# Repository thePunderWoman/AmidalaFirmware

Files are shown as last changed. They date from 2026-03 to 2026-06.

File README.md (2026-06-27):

<p align="center">
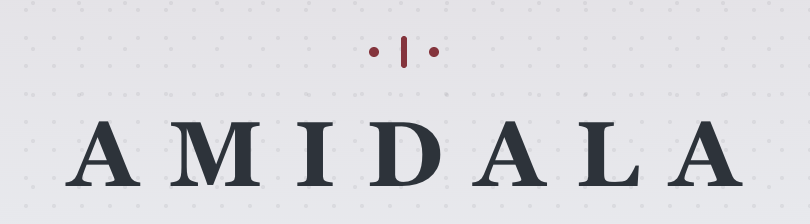
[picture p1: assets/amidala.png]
Amidala
  
</p>

<p align="center">
  <a href="https://github.com/thePunderWoman/Amidala/actions/workflows/ci.yml">
    
  </a>
  <a href="https://github.com/thePunderWoman/Amidala/releases/latest">
    
  </a>
</p>

**Amidala** is an ESP32-S3 firmware for controlling your droids. It runs on the [Amidala PCB](PCB/) — a PCB designed to make wiring a full-featured droid build straightforward — and is compatible with both the N8R2 (8 MB flash) and N16R8 (16 MB flash) module variants.

> **[Amidala Wizards →](https://thepunderwoman.github.io/Amidala/)** — browser-based tools for setting up your droid. Includes a **Config Converter** for migrating Stealth RC / OG Amidala configs to the current format.

---

## Features

- **XBee wireless control** — secure, long-range, low-latency control via XBee 3 modules
- **Multiple Controller Support** — works with classic stealth controllers, Amidala controllers, standard Bluetooth gamepads, and analog RC (PPM) input.
- **Wi-Fi configuration UI** — browser-based interface for fully configuring your droid without needing to pull the SD card.
- **Native HCR support** — full Human Cyborg Relations vocalizer integration.
- **Advanced Dome Drive** — Built-in support for auto dome drive with a Pololu encoder motor and hall sensor, or any other basic PWM dome drive.
- **Flexible drive systems** — PWM, Sabertooth serial, or RoboteQ (PWM, serial, or hybrid)
- **Native built-in safety features** — Web based e-stop, dome obstruction motor disconnect, auto motor disable on controller disconnect.
- **Layers of controller button configurations** — with short-press, long-press, and alt-modifier layers
- **Effectively unlimited serial strings and gestures** — the only limits are your imagination!
- **And more** — I2C aux output, digital outputs, analog inputs, SD card config, servo outputs, and emergency stop handling

---

## Web Configuration UI

<p align="center">
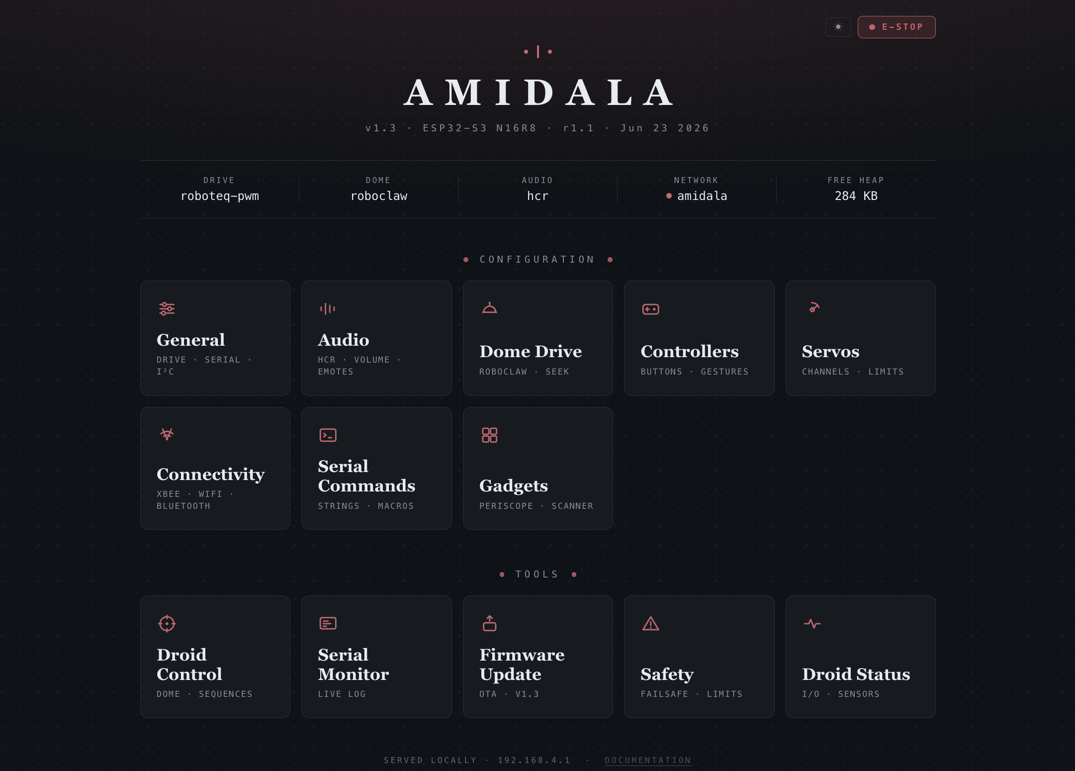
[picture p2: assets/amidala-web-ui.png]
Amidala
  
</p>

The Amidala web interface allows you total control over your droid's configuration. You can set up your controller configuration, which buttons trigger what, add serial commands, set defaults for audio, dome positioning, safety timeouts, emergency stop commands, configure Bluetooth, see digital pin statuses, use the serial monitor, configure your droid's gadgets, and even use the droid control page to trigger sequences, trigger emotes, and dome controls. See more in the wiki.

## Get Started

> **[Documentation Wiki →](https://github.com/thePunderWoman/Amidala/wiki)**

The wiki covers everything from first flash through full configuration. For a quick look at every available config key, see [example_config.txt](example_config.txt) — it's a complete annotated reference used on a real build. Although once you get set up initially, you won't need to look at this file again, as you can update every config option through the web UI.

---

## The Amidala PCB

<p align="center">
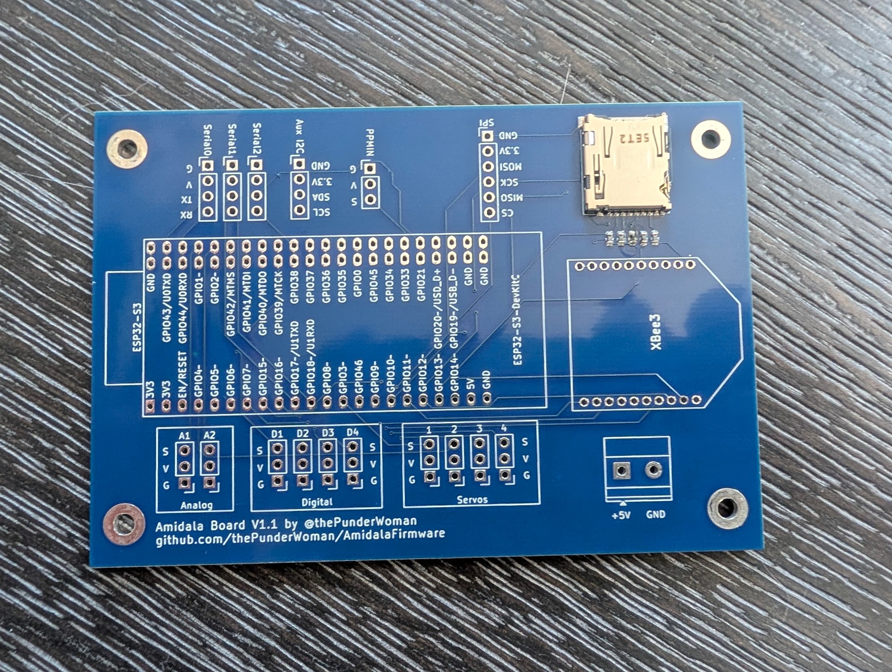
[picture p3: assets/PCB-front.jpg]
Amidala PCB front
  
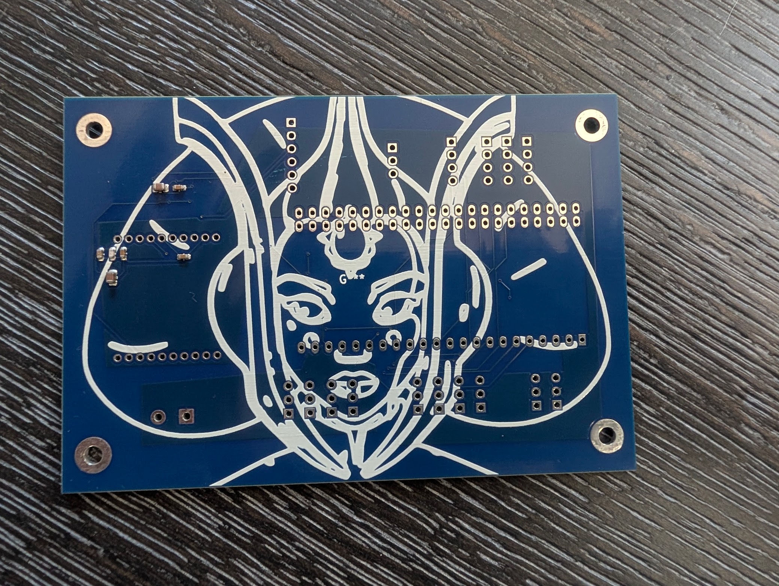
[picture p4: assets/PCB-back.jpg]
Amidala PCB back
  
</p>

The Amidala PCB is a purpose-built carrier for the ESP32-S3, designed to consolidate all the connectors a typical R2 build needs onto a single board:

- 4 servo headers (LEDC PWM)
- 4 digital output pins
- 2 analog inputs
- 3 serial headers (UART0 primary out, UART1 RoboClaw, UART2 aux)
- Auxiliary I2C header
- Native XBee slot (SPI, no adapter needed)
- Micro SD card reader
- Additional SPI breakout
- PPM input for RC receivers

> **[PCB details, schematics, and BOM →](PCB/)**

---

## License

This project is released under the [GNU General Public License v2](LICENSE). You are free to use, modify, and distribute it — including your own modifications — as long as you share the source code of any distributed derivatives under the same license.

---

## Contributing

Bug reports and feature requests are welcome — please use the [issue tracker](https://github.com/thePunderWoman/Amidala/issues).

If you'd like to contribute code, see [CONTRIBUTING.md](CONTRIBUTING.md).

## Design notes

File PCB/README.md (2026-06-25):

# AmidalaBoard (AmidalaShield)

A custom KiCad PCB shield designed specifically for the [Amidala Firmware](https://github.com/thePunderWoman/AmidalaFirmware) — a control system for astromech and similar droid builds. This board provides all the I/O the firmware needs in a single, purpose-built package.

**Designed by [thePunderWoman](https://github.com/thePunderWoman)**

---

## Overview

The AmidalaShield is a carrier/breakout board for the **ESP32-S3 N16R8 DevKit**. It breaks out and conditions the ESP32-S3's peripherals for the specific needs of the Amidala Firmware: wireless XBee communication, multi-channel servo control, RC receiver input, SD card storage, and expansion headers for additional peripherals.

---

## Requirements

- **Microcontroller:** ESP32-S3 N16R8 DevKit (16 MB flash, 8 MB PSRAM)
- **Wireless modules:** XBee3 modules (x2 recommended — one for drive controller, one for dome controller)

---

## Hardware Features

### Wireless Communication
- **XBee3 module socket** for dual-controller operation (drive + dome)

### Servo Control
- **4× PWM servo outputs** — 3-pin headers (signal, power, ground)

### Serial Ports
- **2× hardware serial ports** — UART0 (shared with USB/programming) and UART1
- **1× software serial port** — for additional peripherals

### I/O
- **4× digital I/O pins**
- **2× analog input pins**
- **1× Aux I2C header** — for external I2C devices

### RC Control
- **PPM input (ppmin)** — for analog RC receiver

### Storage
- **Built-in microSD card reader** — used for `config.txt` at startup (matches Amidala Firmware config system)

### Expansion
- **Dedicated SPI header** — for external SPI peripherals

---

## Repository Contents

| File/Folder | Description |
|---|---|
| `AmidalaShield.kicad_sch` | Top-level schematic |
| `comms.kicad_sch` | XBee communications sub-sheet |
| `io.kicad_sch` | Digital/analog I/O sub-sheet |
| `power.kicad_sch` | Power distribution sub-sheet |
| `rc_control.kicad_sch` | RC input sub-sheet |
| `servos.kicad_sch` | Servo output sub-sheet |
| `spi.kicad_sch` | SPI header sub-sheet |
| `gerbers/` | Production-ready Gerber files |
| `libraries/` | Project-specific KiCad symbol/footprint libraries |
| `images/` | Board renders and screenshots |

---

## Getting Started

1. Clone this repo and open `AmidalaShield.kicad_pro` in KiCad 8+.
2. Review the schematics for pin assignments before assembling.
3. Use the Gerber files in `gerbers/` to order PCBs from your preferred fab.
4. Flash your ESP32-S3 with the [Amidala Firmware](https://github.com/thePunderWoman/AmidalaFirmware).
5. Place a `config.txt` on the microSD card — see the firmware repo for a full annotated example.

---

## GPIO Table

> **V1.1** — Updated GPIO assignments for ESP32-S3 WROOM-1 N8R2/N16R2 (Quad flash/PSRAM).
> Avoid GPIO35–37 on R8 (Octal) variants. GPIO48 reserved for onboard RGB LED.

| Function | GPIO | DevKit Side | Notes |
|---|---|---|---|
| **SPI MOSI** | GPIO11 | Left | Native FSPI, shared bus |
| **SPI MISO** | GPIO13 | Left | Native FSPI, shared bus |
| **SPI SCK** | GPIO12 | Left | Native FSPI, shared bus |
| **SD Card CS** | GPIO10 | Left | |
| **XBee CS** | GPIO7 | Left | |
| **SPI Spare CS** | GPIO14 | Left | Exposed header |
| **XBee ATTN** | GPIO16 | Left | |
| **XBee SLEEP** | GPIO15 | Left | |
| **I2C SDA** | GPIO8 | Left | Native I2C default |
| **I2C SCL** | GPIO9 | Left | Native I2C default |
| **UART0 TX** | GPIO43 | Right | Shared w/ USB — do not use simultaneously |
| **UART0 RX** | GPIO44 | Right | Shared w/ USB — do not use simultaneously |
| **UART1 TX** | GPIO17 | Right | Primary droid brain serial |
| **UART1 RX** | GPIO18 | Right | |
| **SW-UART TX** | GPIO21 | Right | |
| **SW-UART RX** | GPIO38 | Right | |
| **PPMIN** | GPIO47 | Right | |
| **Analog 1** | GPIO1 | Right | ADC1_0, WiFi-safe |
| **Analog 2** | GPIO2 | Right | ADC1_1, WiFi-safe |
| **Servo 1** | GPIO3 | Left | Strapping pin (JTAG source), safe after boot |
| **Servo 2** | GPIO4 | Left | |
| **Servo 3** | GPIO5 | Left | |
| **Servo 4** | GPIO6 | Left | |
| **Digital 1** | GPIO39 | Right | Goes HIGH after reset (not LOW like most GPIOs) |
| **Digital 2** | GPIO40 | Right | |
| **Digital 3** | GPIO41 | Right | |
| **Digital 4** | GPIO42 | Right | Transitions low on reset slightly slower |
| **RGB LED** | GPIO48 | Right | Reserved — onboard DevKit RGB LED |
| **NC** | GPIO8 | Left | Reserved |

### Pins Intentionally Avoided

| GPIO | Reason |
|---|---|
| GPIO0 | Strapping pin — boot mode |
| GPIO3 | Strapping pin — JTAG source (used for Servo 1, safe after boot) |
| GPIO19/20 | USB D-/D+ |
| GPIO26–32 | Internal SPI flash/PSRAM — never use |
| GPIO35–37 | Internal on Octal (R8) variants — safe on R2 only |
| GPIO45 | Strapping pin — VDD_SPI voltage |
| GPIO46 | Strapping pin |

---

## License

This hardware design is licensed under the [Creative Commons Attribution-NonCommercial-ShareAlike 4.0 International License](LICENSE.md) (CC BY-NC-SA 4.0).

You are free to share and adapt this design for non-commercial purposes, as long as you give appropriate credit and distribute any adaptations under the same license.

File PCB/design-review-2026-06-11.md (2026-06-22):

# AmidalaShield Design Review — 2026-06-11

**Board:** AmidalaShield v1.1  
**Size:** 100.05 × 75.05mm (4-layer)  
**Stackup:** F.Cu (signal) / In1.Cu (GND) / In2.Cu (GND) / B.Cu (+3.3V + +5V zones)  
**Verdict: CLEAR TO FAB — no open blockers**

---

## Analyses Run

| Analyzer | Status |
|---|---|
| Schematic (`analyze_schematic.py`) | ✓ Complete |
| PCB (`analyze_pcb.py --full`) | ✓ Complete |
| Gerbers (`analyze_gerbers.py`) | ✓ Complete — fresh export 2026-06-11 |
| Cross-analysis (`cross_analysis.py`) | ✓ Complete |
| Thermal (`analyze_thermal.py`) | ✓ Complete — score 100/100, 0 findings |
| SPICE | Skipped — no simulator installed |
| Datasheet sync | Skipped — MPNs not required (see below) |

---

## Board Summary

- **Components:** 32 (26 unique BOM lines)
- **Nets:** 55
- **Footprints on PCB:** 37 (includes REF** mounting/logo and G*** Amidala logo)
- **Vias:** 359 total (333 GND stitching)
- **Total holes:** 506
- **Layers:** 4
- **Fab tier:** ≤100×100mm standard pricing

---

## BOM

| Value | Qty | Footprint | Refs |
|---|-----|---|---|
| 100n | 3 | C_0603_1608Metric | C1, C2, C3 |
| 1µ | 1 | C_0603_1608Metric | C5 |
| 8.2p | 1 | C_0603_1608Metric | C6 |
| 10µ | 2 | C_0805_2012Metric | C4, C7 |
| 100µF | 1 | CP_EIA-3216-18_Kemet-A (tantalum) | C9 |
| 10k | 4 | R_0603_1608Metric | R1, R2, R3, R5 |
| ESP32-S3-DevKitC | 1 | Custom (verified) | ESP32-S3 |
| XB3-24Z8UT-J | 1 | XB324Z8UTJ | XBee3 |
| Micro SD | 1 | Hirose DM3AT-SF-PEJM5 | J3 |
| Screw terminal 2-pos | 1 | Phoenix MKDS-1.5-2 5.08mm | J1 |
| Headers (various) | 11 | PinHeader 2.54mm | I2C1, SPI1, Serial0/1, SWSerial1, J_Servo1–4, J_Digital1–4, J_Analog1–2, J_PPMIN1 |

---

## Findings

### Blockers
**None.**

---

### Warnings (all accepted / known false positives)

| ID | Finding | Disposition |
|----|---|---|
| RS-001 | +3.3V and +5V have no declared source | **False positive** — PWR_FLAGs correctly stacked: #FLG04 on +5V, #FLG05 on GND, #FLG01 on +3.3V |
| SS-001 | 1/26 BOM lines have MPNs | **Accepted** — fab picks basic passives; remaining parts are headers/connectors |
| DS-002 | No datasheets directory | **Accepted** — MPNs not required for this build |
| PS-002 | GND plane: 334 islands | **False positive** — 333 GND stitching vias counted individually by island detector |
| PS-002 | +3.3V plane: 3 islands | **False positive** — 3 intentional B.Cu pour regions, verified correct in KiCad |
| RP-002 | 8 SPI signals crossing GND plane gap | **Structural / accepted** — no GND zone on outer layers by design; return path through inner planes; acceptable at <10MHz SPI |
| PM-001 | Courtyard overlaps: C1/C2/C5/C6/C7 ↔ XBee3 | **Accepted** — XBee3 is a through-hole footprint; overlaps suppressed in `.kicad_dru` |
| GR-002 | Copper/edge layer alignment variance (6.0mm W, 3.9mm H) | **Expected** — copper clearance from board edge |
| GR-004 | F.Paste: 76 flashes vs 1096 copper (7%) | **Expected** — THT-dominant design |
| TE-001 | 0/60 nets have test points | **Accepted** — deferred to future revision |
| VS-002 | Via stitching sparse on 50% of board | **Accepted** — 333 stitching vias present; sparse areas are connectors/headers |

---

### Info (no action)

| ID | Finding | Note |
|----|---|---|
| CERT-001 | Wireless module detected: ESP32-S3 | Expected — core MCU |
| CP-002 | No opposite-layer copper under THT/header parts | Expected — inner plane design |
| FD-001 | No fiducials on F.Cu | Acceptable — coarsest SMD pitch is 0.70mm, no fine-pitch parts |
| XV-001 | REF** and G*** in PCB but not schematic | Expected — mounting holes and Amidala logo graphic |
| B.SilkS overrun | Logo extends past board edge | **Accepted** — cosmetic; fab will trim |
| RC-DET | R1/C1 RC filter at 159.15Hz | Correct — XBee3 power-on reset delay |
| TS-DET | 333 GND stitching vias, 1 +3.3V via | Correct — matches intent |
| EP-AUD | No ESD protection on headers/connectors | Accepted — internal RC robot controller |

---

## Thermal

Score: **100/100** — 0 findings. No thermal concerns at expected operating loads.

---

## Gerbers

Regenerated 2026-06-11. Files in `gerbers/AmidalaShield-gerbers.zip`.

| Layer | File |
|---|---|
| F.Cu | AmidalaShield-F_Cu.gtl |
| In1.Cu (GND) | AmidalaShield-In1_Cu.g1 |
| In2.Cu (GND) | AmidalaShield-In2_Cu.g2 |
| B.Cu (+3.3V/+5V) | AmidalaShield-B_Cu.gbl |
| F.Mask | AmidalaShield-F_Mask.gts |
| B.Mask | AmidalaShield-B_Mask.gbs |
| F.Silkscreen | AmidalaShield-F_Silkscreen.gto |
| B.Silkscreen | AmidalaShield-B_Silkscreen.gbo |
| F.Paste | AmidalaShield-F_Paste.gtp |
| B.Paste | AmidalaShield-B_Paste.gbp |
| Edge.Cuts | AmidalaShield-Edge_Cuts.gm1 |
| PTH drill | AmidalaShield-PTH-drl.gbr |
| NPTH drill | AmidalaShield-NPTH-drl.gbr |

---

## Design Decisions on Record

- **R4 removed:** SPI CLK pull-up (GPIO12) removed in v1.1. CPOL=1 constraint lifted; firmware can select any SPI mode. GPIO12 floats during boot before SPI peripheral initializes — bring-up note for XBee3.
- **C9 added:** 100µF tantalum on +5V for servo transient suppression.
- **Zone stack:** GND on In1+In2, power (+3.3V/+5V) on B.Cu, signal only on F.Cu. All SMD on F.Cu for single-side reflow.
- **ESP32-S3 footprint:** Custom footprint verified by designer — do not flag.
- **XBee3 courtyard:** THT footprint; courtyard warnings suppressed in `.kicad_dru` and should always be ignored.

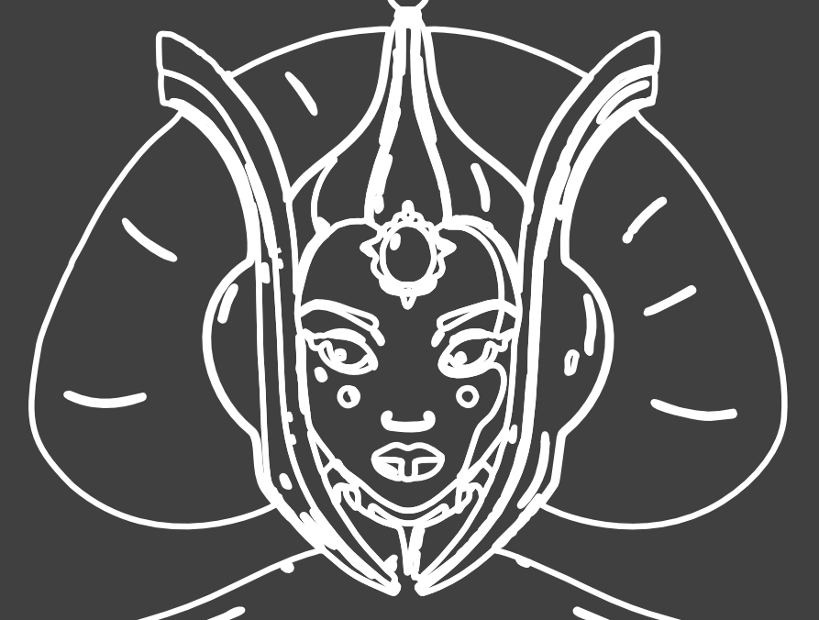
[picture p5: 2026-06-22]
PCB/images/amidala-screen.png

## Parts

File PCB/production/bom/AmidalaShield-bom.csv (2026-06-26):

Id | Designator | Footprint | Quantity | Designation | Supplier and ref
1 | R3,R1,R2,R5 | R_0603_1608Metric | 4 | 10k
2 | C4,C7 | C_0805_2012Metric | 2 | 10u
3 | C2,C1,C3 | C_0603_1608Metric | 3 | 100n
4 | C9 | CP_EIA-3216-18_Kemet-A | 1 | 100µF
5 | J3 | microSD_HC_Hirose_DM3AT-SF-PEJM5 | 1 | Micro_SD_Card
6 | C6 | C_0603_1608Metric | 1 | 8.2p
7 | C5 | C_0603_1608Metric | 1 | 1u

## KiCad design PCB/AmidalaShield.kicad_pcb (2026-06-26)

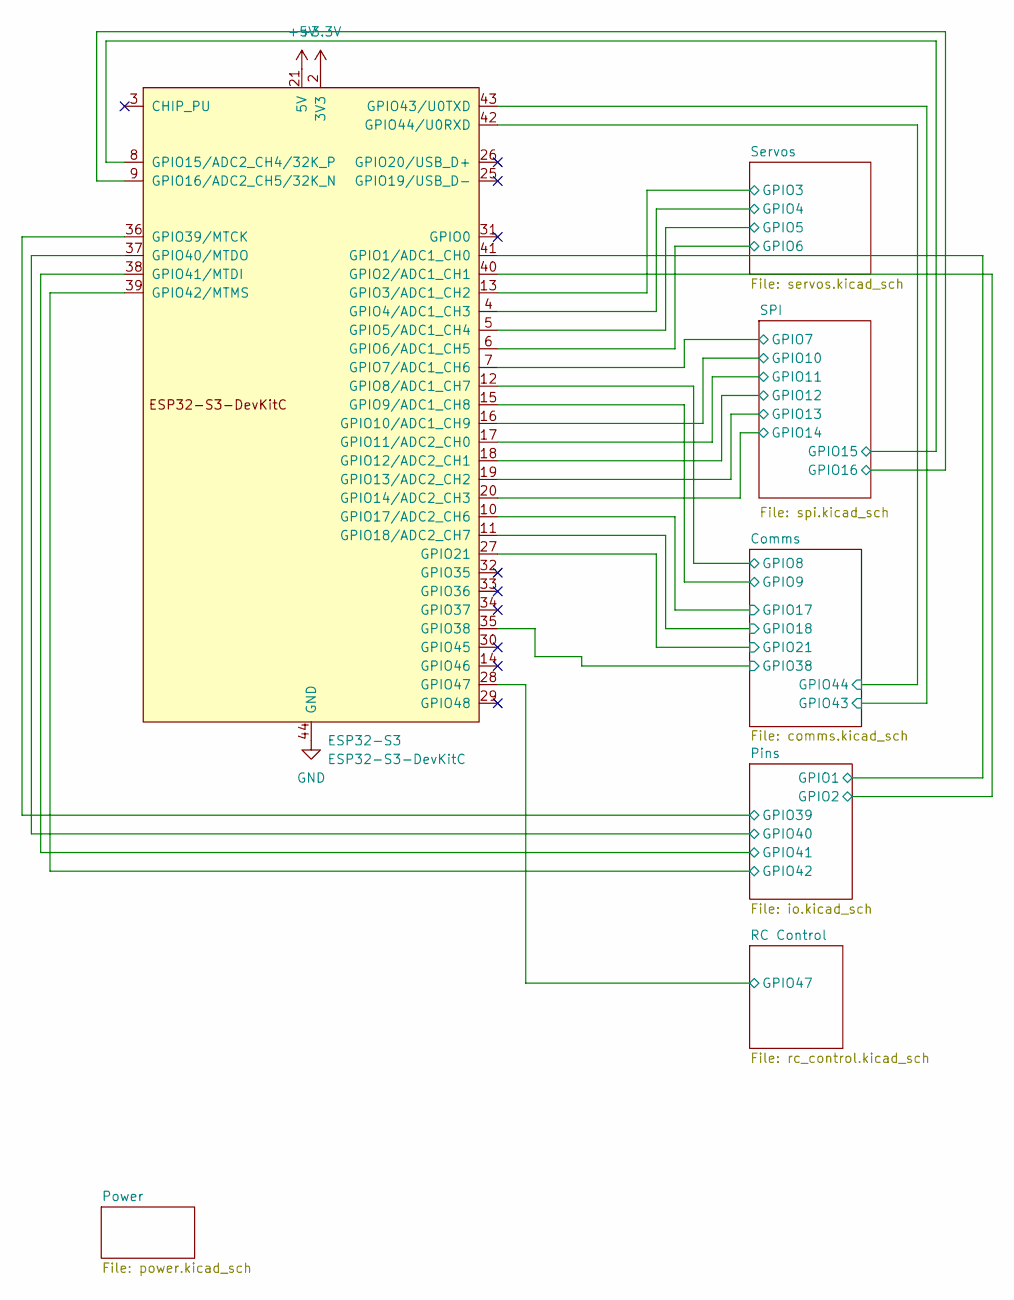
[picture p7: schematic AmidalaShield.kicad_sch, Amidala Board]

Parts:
ESP32-S3: ESP32-S3-DevKitC; ESP32-S2-DevKitC-1

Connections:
+3.3V: ESP32-S3.1 (3V3), ESP32-S3.2 (3V3); also elsewhere on the board
+5V: ESP32-S3.21 (5V); also elsewhere on the board
/Comms/GPIO8: ESP32-S3.12 (GPIO8/ADC1_CH7); also elsewhere on the board
/Comms/GPIO9: ESP32-S3.15 (GPIO9/ADC1_CH8); also elsewhere on the board
/Comms/GPIO17: ESP32-S3.10 (GPIO17/ADC2_CH6); also elsewhere on the board
/Comms/GPIO18: ESP32-S3.11 (GPIO18/ADC2_CH7); also elsewhere on the board
/Comms/GPIO21: ESP32-S3.27 (GPIO21); also elsewhere on the board
/Comms/GPIO38: ESP32-S3.35 (GPIO38); also elsewhere on the board
/Comms/GPIO43: ESP32-S3.43 (GPIO43/U0TXD); also elsewhere on the board
/Comms/GPIO44: ESP32-S3.42 (GPIO44/U0RXD); also elsewhere on the board
/Pins/GPIO1: ESP32-S3.41 (GPIO1/ADC1_CH0); also elsewhere on the board
/Pins/GPIO2: ESP32-S3.40 (GPIO2/ADC1_CH1); also elsewhere on the board
/Pins/GPIO39: ESP32-S3.36 (GPIO39/MTCK); also elsewhere on the board
/Pins/GPIO40: ESP32-S3.37 (GPIO40/MTDO); also elsewhere on the board
/Pins/GPIO41: ESP32-S3.38 (GPIO41/MTDI); also elsewhere on the board
/Pins/GPIO42: ESP32-S3.39 (GPIO42/MTMS); also elsewhere on the board
/RC Control/GPIO47: ESP32-S3.28 (GPIO47); also elsewhere on the board
/SPI/GPIO7: ESP32-S3.7 (GPIO7/ADC1_CH6); also elsewhere on the board
/SPI/GPIO10: ESP32-S3.16 (GPIO10/ADC1_CH9); also elsewhere on the board
/SPI/GPIO11: ESP32-S3.17 (GPIO11/ADC2_CH0); also elsewhere on the board
/SPI/GPIO12: ESP32-S3.18 (GPIO12/ADC2_CH1); also elsewhere on the board
/SPI/GPIO13: ESP32-S3.19 (GPIO13/ADC2_CH2); also elsewhere on the board
/SPI/GPIO14: ESP32-S3.20 (GPIO14/ADC2_CH3); also elsewhere on the board
/SPI/GPIO15: ESP32-S3.8 (GPIO15/ADC2_CH4/32K_P); also elsewhere on the board
/SPI/GPIO16: ESP32-S3.9 (GPIO16/ADC2_CH5/32K_N); also elsewhere on the board
/Servos/GPIO3: ESP32-S3.13 (GPIO3/ADC1_CH2); also elsewhere on the board
/Servos/GPIO4: ESP32-S3.4 (GPIO4/ADC1_CH3); also elsewhere on the board
/Servos/GPIO5: ESP32-S3.5 (GPIO5/ADC1_CH4); also elsewhere on the board
/Servos/GPIO6: ESP32-S3.6 (GPIO6/ADC1_CH5); also elsewhere on the board
GND: ESP32-S3.22 (GND), ESP32-S3.23 (GND), ESP32-S3.24 (GND), ESP32-S3.44 (GND); also elsewhere on the board

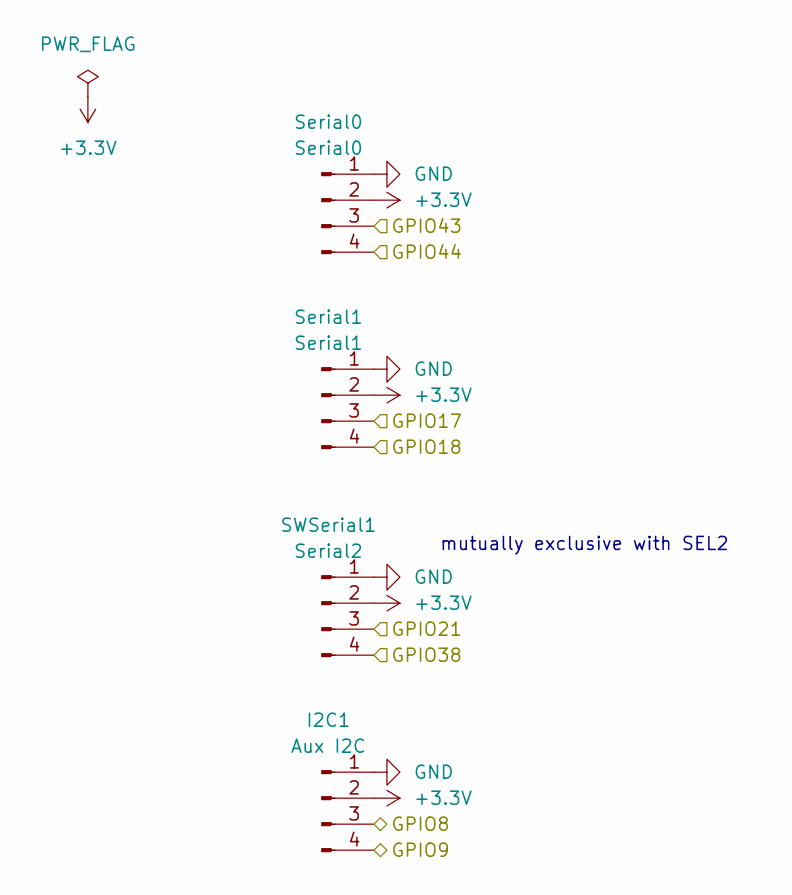
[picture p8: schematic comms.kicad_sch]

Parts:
I2C1: Aux I2C; PinHeader_1x04_P2.54mm_Vertical
SWSerial1: Serial2; PinHeader_1x04_P2.54mm_Vertical
Serial0: Serial0; PinHeader_1x04_P2.54mm_Vertical
Serial1: Serial1; PinHeader_1x04_P2.54mm_Vertical

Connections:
+3.3V: I2C1.2, SWSerial1.2, Serial0.2, Serial1.2; also elsewhere on the board
/Comms/GPIO8: I2C1.3; also elsewhere on the board
/Comms/GPIO9: I2C1.4; also elsewhere on the board
/Comms/GPIO17: Serial1.3; also elsewhere on the board
/Comms/GPIO18: Serial1.4; also elsewhere on the board
/Comms/GPIO21: SWSerial1.3; also elsewhere on the board
/Comms/GPIO38: SWSerial1.4; also elsewhere on the board
/Comms/GPIO43: Serial0.3; also elsewhere on the board
/Comms/GPIO44: Serial0.4; also elsewhere on the board
GND: I2C1.1, SWSerial1.1, Serial0.1, Serial1.1; also elsewhere on the board

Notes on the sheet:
mutually exclusive with SEL2

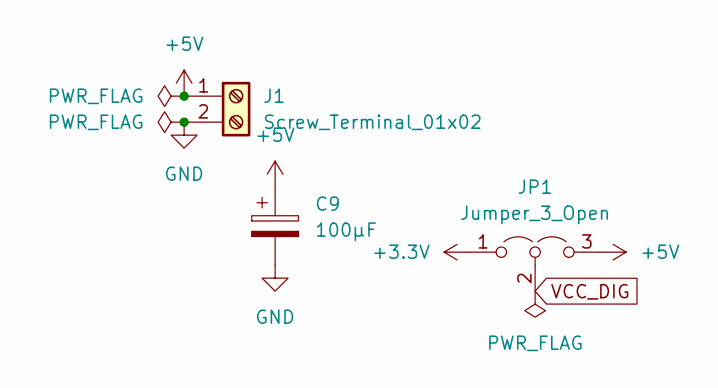
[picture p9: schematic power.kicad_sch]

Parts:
C9: 100µF; CP_EIA-3216-18_Kemet-A
J1: Screw_Terminal_01x02; TerminalBlock_Phoenix_MKDS-1,5-2-5.08_1x02_P5.08mm_Horizont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
JP1: Jumper_3_Open; PinHeader_1x03_P2.54mm_Vertical

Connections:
+3.3V: JP1.1 (A); also elsewhere on the board
+5V: C9.1, J1.1, JP1.3 (B); also elsewhere on the board
GND: C9.2, J1.2; also elsewhere on the board
VCC_DIG: JP1.2 (C); also elsewhere on the board

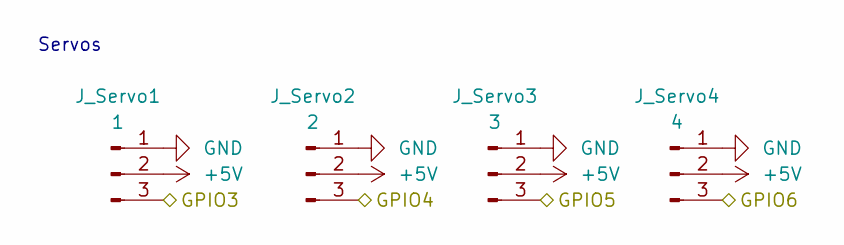
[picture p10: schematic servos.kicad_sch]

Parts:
J_Servo1: 1; PinHeader_1x03_P2.54mm_Vertical
J_Servo2: 2; PinHeader_1x03_P2.54mm_Vertical
J_Servo3: 3; PinHeader_1x03_P2.54mm_Vertical
J_Servo4: 4; PinHeader_1x03_P2.54mm_Vertical

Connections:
+5V: J_Servo1.2, J_Servo2.2, J_Servo3.2, J_Servo4.2; also elsewhere on the board
/Servos/GPIO3: J_Servo1.3; also elsewhere on the board
/Servos/GPIO4: J_Servo2.3; also elsewhere on the board
/Servos/GPIO5: J_Servo3.3; also elsewhere on the board
/Servos/GPIO6: J_Servo4.3; also elsewhere on the board
GND: J_Servo1.1, J_Servo2.1, J_Servo3.1, J_Servo4.1; also elsewhere on the board

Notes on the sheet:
Servos

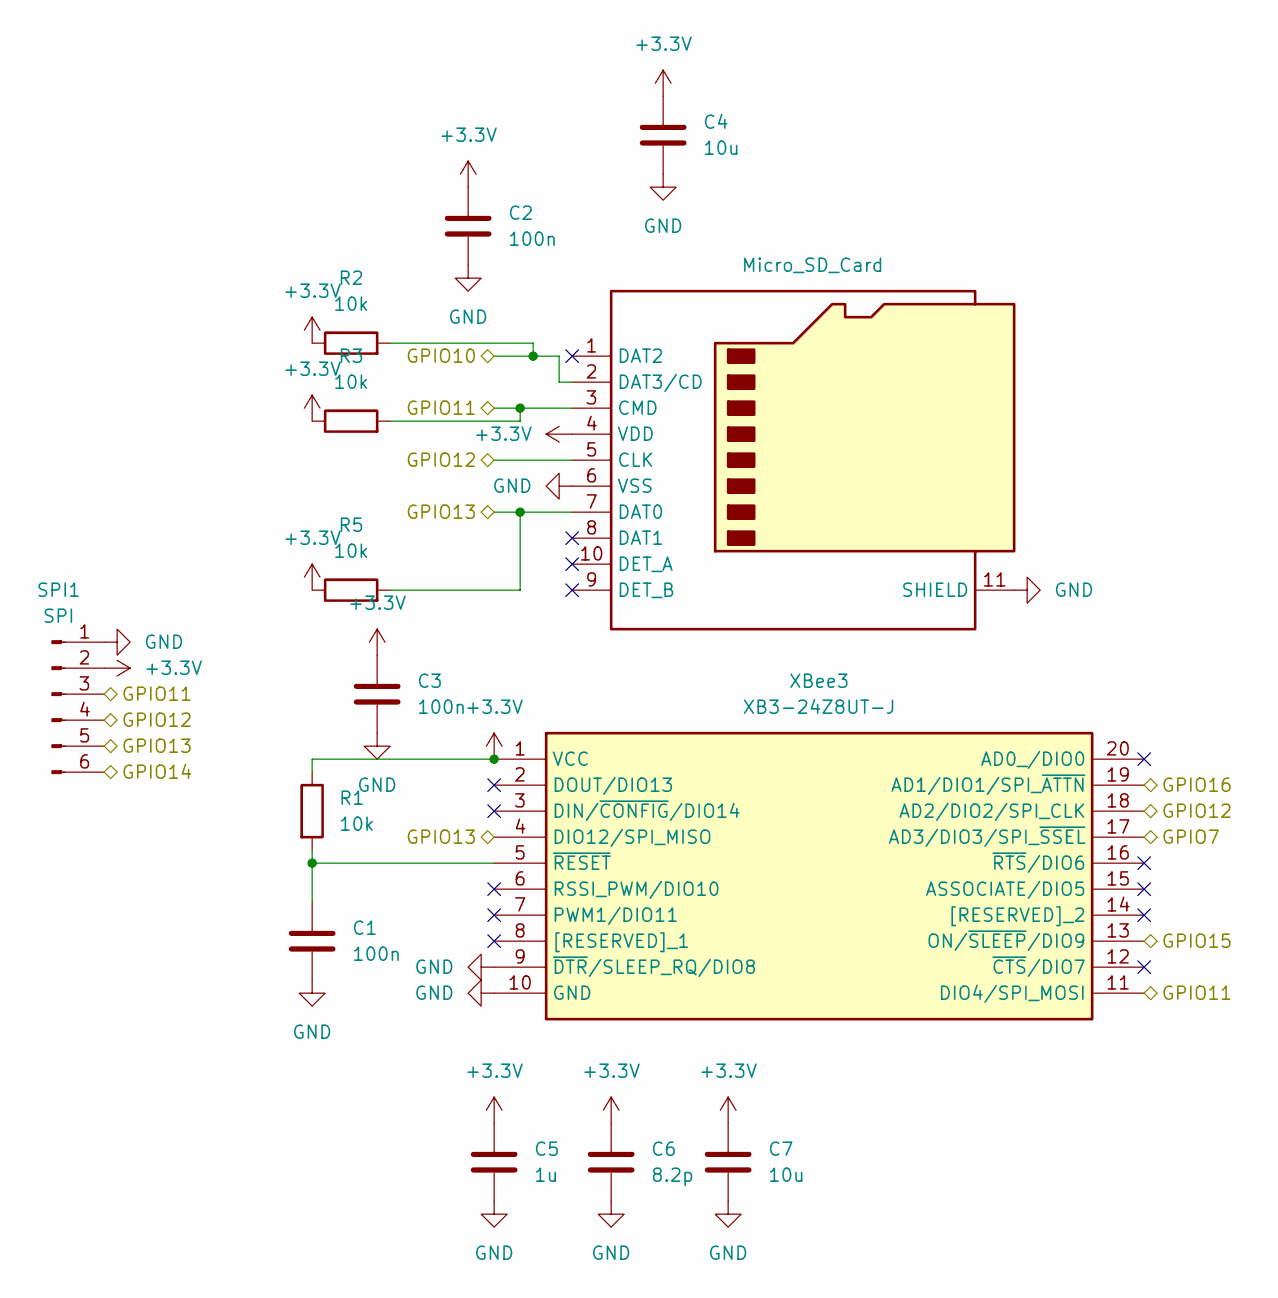
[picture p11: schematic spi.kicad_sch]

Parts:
C1, C2, C3: 100n; C_0603_1608Metric
C4, C7: 10u; C_0805_2012Metric
C5: 1u; C_0603_1608Metric
C6: 8.2p; C_0603_1608Metric
J3: Micro_SD_Card; microSD_HC_Hirose_DM3AT-SF-PEJM5
R1, R2, R3, R5: 10k; R_0603_1608Metric
SPI1: SPI; PinHeader_1x06_P2.54mm_Vertical
XBee3: XB3-24Z8UT-J; XB324Z8UTJ; Mouser Part Number 888-XB3-24Z8UT-J

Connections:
+3.3V: C2.1, C3.1, C4.1, C5.1, C6.1, C7.1, J3.4 (VDD), R1.1, R2.1, R3.1, R5.1, SPI1.2, XBee3.1 (VCC); also elsewhere on the board
/SPI/GPIO7: XBee3.17 (AD3/DIO3/SPI_~SSEL); also elsewhere on the board
/SPI/GPIO10: J3.2 (DAT3/CD), R2.2; also elsewhere on the board
/SPI/GPIO11: J3.3 (CMD), R3.2, SPI1.3, XBee3.11 (DIO4/SPI_MOSI); also elsewhere on the board
/SPI/GPIO12: J3.5 (CLK), SPI1.4, XBee3.18 (AD2/DIO2/SPI_CLK); also elsewhere on the board
/SPI/GPIO13: J3.7 (DAT0), R5.2, SPI1.5, XBee3.4 (DIO12/SPI_MISO); also elsewhere on the board
/SPI/GPIO14: SPI1.6; also elsewhere on the board
/SPI/GPIO15: XBee3.13 (ON/~SLEEP/DIO9); also elsewhere on the board
/SPI/GPIO16: XBee3.19 (AD1/DIO1/SPI_~ATTN); also elsewhere on the board
GND: C1.2, C2.2, C3.2, C4.2, C5.2, C6.2, C7.2, J3.6 (VSS), J3.11 (SHIELD), SPI1.1, XBee3.9 (~DTR/SLEEP_RQ/DIO8), XBee3.10 (GND); also elsewhere on the board
unnamed: C1.1, R1.2, XBee3.5 (~RESET)

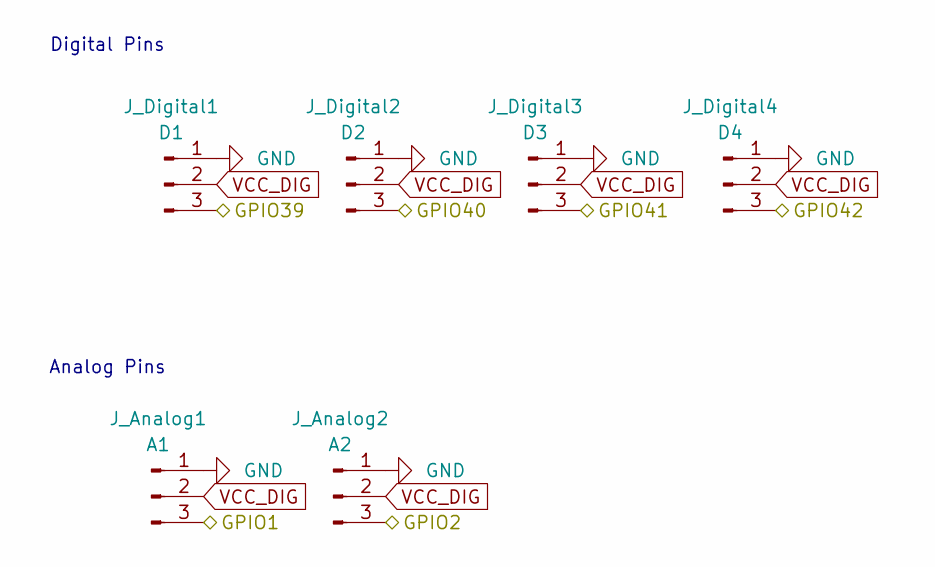
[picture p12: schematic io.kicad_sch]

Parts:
J_Analog1: A1; PinHeader_1x03_P2.54mm_Vertical
J_Analog2: A2; PinHeader_1x03_P2.54mm_Vertical
J_Digital1: D1; PinHeader_1x03_P2.54mm_Vertical
J_Digital2: D2; PinHeader_1x03_P2.54mm_Vertical
J_Digital3: D3; PinHeader_1x03_P2.54mm_Vertical
J_Digital4: D4; PinHeader_1x03_P2.54mm_Vertical

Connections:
/Pins/GPIO1: J_Analog1.3; also elsewhere on the board
/Pins/GPIO2: J_Analog2.3; also elsewhere on the board
/Pins/GPIO39: J_Digital1.3; also elsewhere on the board
/Pins/GPIO40: J_Digital2.3; also elsewhere on the board
/Pins/GPIO41: J_Digital3.3; also elsewhere on the board
/Pins/GPIO42: J_Digital4.3; also elsewhere on the board
GND: J_Analog1.1, J_Analog2.1, J_Digital1.1, J_Digital2.1, J_Digital3.1, J_Digital4.1; also elsewhere on the board
VCC_DIG: J_Analog1.2, J_Analog2.2, J_Digital1.2, J_Digital2.2, J_Digital3.2, J_Digital4.2; also elsewhere on the board

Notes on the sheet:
Analog Pins
Digital Pins

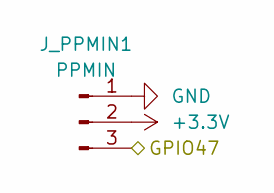
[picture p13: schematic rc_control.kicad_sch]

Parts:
J_PPMIN1: PPMIN; PinHeader_1x03_P2.54mm_Vertical

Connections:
+3.3V: J_PPMIN1.2; also elsewhere on the board
/RC Control/GPIO47: J_PPMIN1.3; also elsewhere on the board
GND: J_PPMIN1.1; also elsewhere on the board

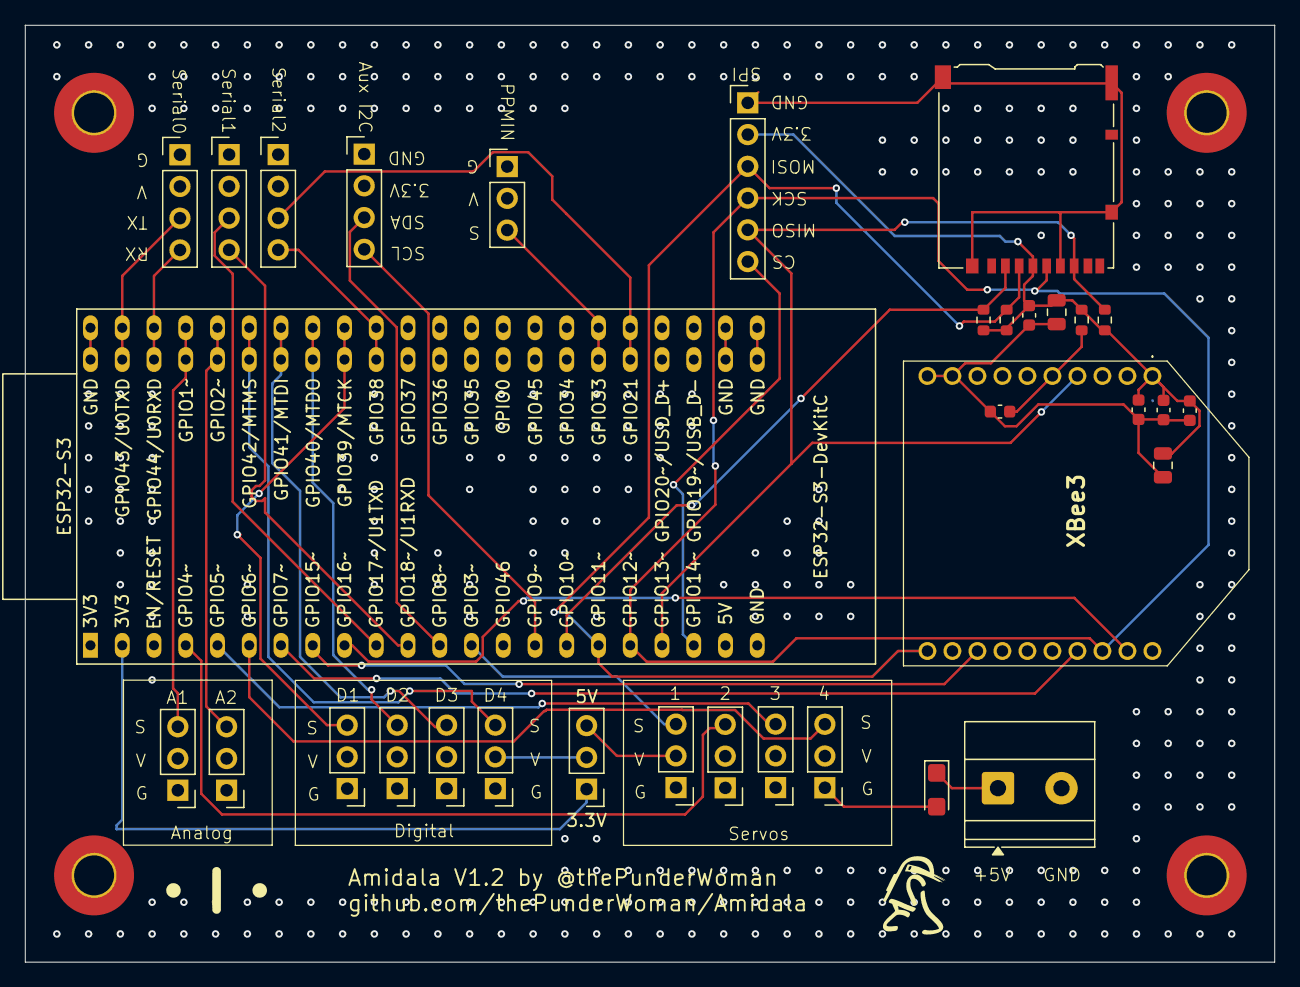
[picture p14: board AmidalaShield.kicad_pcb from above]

Board: 4 copper layers, 99.9 x 74.9 mm, 33 parts (0 on the bottom side), 32 nets.

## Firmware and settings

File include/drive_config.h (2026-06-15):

// drive_config.h
// Drive and dome system configuration for Amidala Firmware.
//
// Edit the two "Active selection" lines to switch hardware configurations.
// Everything below the "Drive system resolution" comment is derived
// automatically — do not edit those lines.

#pragma once

// ---- Drive system type constants --------------------------------------------

#define DRIVE_SYSTEM_PWM                1
#define DRIVE_SYSTEM_SABER              2
#define DRIVE_SYSTEM_ROBOTEQ_PWM        3
#define DRIVE_SYSTEM_ROBOTEQ_SERIAL     4
#define DRIVE_SYSTEM_ROBOTEQ_PWM_SERIAL 5

// Active selection (uncomment the one in use):
// #define DRIVE_SYSTEM DRIVE_SYSTEM_ROBOTEQ_PWM_SERIAL
#define DRIVE_SYSTEM DRIVE_SYSTEM_ROBOTEQ_PWM

// ---- Dome drive type constants -----------------------------------------------

#define DOME_DRIVE_SABER    2
#define DOME_DRIVE_PWM      3
#define DOME_DRIVE_ROBOCLAW 4

// Active selection (uncomment the one in use):
// #define DOME_DRIVE DOME_DRIVE_PWM
// #define DOME_DRIVE DOME_DRIVE_SABER
#define DOME_DRIVE DOME_DRIVE_ROBOCLAW

// ---- Speed and acceleration parameters --------------------------------------

#define MAXIMUM_SPEED       1.0f  // percentage 0.0 - 1.0. default 50%
#define MAXIMUM_GUEST_SPEED 0.5f  // percentage 0.0 - 1.0. default 30%
#define DOME_MAXIMUM_SPEED  1.0f  // percentage 0.0 - 1.0. default 100%

// Scale value of 1 means instant. Scale value of 100 means that the throttle
// will increase 1/100 every 25ms
#define ACCELERATION_SCALE 100
// Scale value of 1 means instant. Scale value of 20 means that the throttle
// will decrease 1/20 every 25ms
#define DECELRATION_SCALE  20

// Set to true if acceleration/deceleration should be applied
#define SCALING false

// ---- Dome motion defaults ---------------------------------------------------

#define DEFAULT_DOME_HOME_POSITION      50
#define DEFAULT_DOME_ACCELERATION_SCALE 20
#define DEFAULT_DOME_DECELERATION_SCALE 50
#define DEFAULT_DOME_SEEK_MIN_DELAY     6
#define DEFAULT_DOME_SEEK_MAX_DELAY     8
#define DEFAULT_DOME_TARGET_MIN_DELAY   0
#define DEFAULT_DOME_TARGET_MAX_DELAY   1
#define DEFAULT_DOME_SEEK_LEFT          80
#define DEFAULT_DOME_SEEK_RIGHT         80
#define DEFAULT_DOME_FUDGE              10
#define DEFAULT_DOME_SPEED_HOME         40
#define DEFAULT_DOME_SPEED_SEEK         60
#define DEFAULT_DOME_SPEED_TARGET       100
#define DEFAULT_DOME_SPEED_MIN          5
#define DEFAULT_DOME_DECEL_ZONE         30
#define DEFAULT_DOME_TIMEOUT            5
#define DEFAULT_DOME_INVERTED           true
#define DEFAULT_DOME_MIN_PULSE          1000
#define DEFAULT_DOME_MAX_PULSE          2000

// ---- RoboClaw dome drive defaults -------------------------------------------
// These apply only when DOME_DRIVE == DOME_DRIVE_ROBOCLAW.

// Serial port used by the RoboClaw.
// UART1 (GPIO17/18) — Serial0 (UART0) carries the WCB downstream output.
// DOME_DRIVE_SERIAL is intentionally NOT defined here so pin_config.h still
// assigns SERIAL = Serial0 for the primary output.
#if DOME_DRIVE == DOME_DRIVE_ROBOCLAW
#define ROBOCLAW_SERIAL    Serial1   // UART1, GPIO17/18
#define ROBOCLAW_RX_PIN    18        // UART1 RX
#define ROBOCLAW_TX_PIN    17        // UART1 TX
#define ROBOCLAW_BAUD_RATE 38400
#endif

// Default RoboClaw hardware settings
#define DEFAULT_DOME_ROBOCLAW_ADDRESS 128  // packet-serial default address (0x80)
#define DEFAULT_DOME_ROBOCLAW_CHANNEL 1    // motor channel: 1 = M1, 2 = M2

// Encoder counts per motor shaft revolution (CPR).
// For the Pololu motor in this build the CPR is 1200.
// Change this constant if a different motor is swapped in; it is not a
// runtime config key because it is a hardware property of the motor itself.
#define DOME_MOTOR_CPR 1200

// Max encoder pulses per second sent to RoboClaw SpeedM1/M2.
// Tune this to the motor's realistic no-load maximum before applying load.
#define DEFAULT_DOME_ROBOCLAW_QPPS 800

// Milliseconds of zero encoder movement while the motor is commanded before
// the system declares an obstruction and stops.
#define DEFAULT_DOME_STALL_TIMEOUT_MS 500

// Milliseconds allowed for the homing sweep to find the hall sensor.
// If it expires the system falls back to manual mode with a console warning.
#define DEFAULT_DOME_HOMING_TIMEOUT_MS 15000

// Speed (fraction of QPPS) used during automatic homing and calibration.
// Keep these low enough to be safe on first power-on.
#define DEFAULT_DOME_HOMING_SPEED   0.20f  // 20 % of QPPS
#define DEFAULT_DOME_CALIBRATE_SPEED 0.30f // 30 % of QPPS

// Hardware debounce window for the hall-effect sensor interrupt (ms).
// Triggers arriving faster than this are ignored.
#define DEFAULT_DOME_HALL_DEBOUNCE_MS 50

// Number of complete dome revolutions averaged during calibration.
#define DOME_CALIBRATION_ROTATIONS 10

// Sequence-pause watchdog (dome=seqon[,<seconds>]).  If no dome=seqoff arrives
// within the pause window, the pause auto-clears so the dome resumes its
// normal auto-behaviors even if the body/dome controller crashes mid-sequence.
#define DEFAULT_DOME_SEQUENCE_PAUSE_MS 30000   // 30s default when no arg given
#define DOME_SEQUENCE_PAUSE_MAX_MS     300000  // 5 min safety cap

// EEPROM layout for RoboClaw calibration data.
// Stored at a fixed offset well past the existing SC23 XBee block (0x64)
// and servo block (0xEA) to avoid collisions.
//
//   Offset  Size  Contents
//   0x200   4     Signature bytes: 'R','C','0','1'
//   0x204   4     int32_t  ticksPerDomeRev  (0 → not yet calibrated)
//
// Reading: if the 4-byte signature matches, load ticksPerDomeRev.
// Writing: always write both signature and data atomically.
#define DOME_ROBOCLAW_EEPROM_ADDR 0x200
#define DOME_ROBOCLAW_EEPROM_SIG0 'R'
#define DOME_ROBOCLAW_EEPROM_SIG1 'C'
#define DOME_ROBOCLAW_EEPROM_SIG2 '0'
#define DOME_ROBOCLAW_EEPROM_SIG3 '1'

// ---- Drive system resolution (derived — do not edit) ------------------------

#if DRIVE_SYSTEM == DRIVE_SYSTEM_SABER
#define DRIVE_SERIAL      Serial0   // UART0, GPIO43/44
#define DOME_DRIVE_SERIAL DRIVE_SERIAL
#define CHANNEL_MIXING    true  // premix channels before sending commands
#elif DRIVE_SYSTEM == DRIVE_SYSTEM_PWM
#define CHANNEL_MIXING    false // motor controller will mix the channels
#elif DRIVE_SYSTEM == DRIVE_SYSTEM_ROBOTEQ_PWM
#define CHANNEL_MIXING    false // motor controller will mix the channels
#elif DRIVE_SYSTEM == DRIVE_SYSTEM_ROBOTEQ_SERIAL
#define DRIVE_BAUD_RATE   115200
#define CHANNEL_MIXING    false // motor controller will mix the channels
#elif DRIVE_SYSTEM == DRIVE_SYSTEM_ROBOTEQ_PWM_SERIAL
#define DRIVE_BAUD_RATE   115200
#define CHANNEL_MIXING    false // motor controller will mix the channels
#else
#error Unsupported DRIVE_SYSTEM
#endif

// #define EXPERIMENTAL_JEVOIS_STEERING

#if !defined(DRIVE_BAUD_RATE) && DOME_DRIVE == DOME_DRIVE_SABER
#define DRIVE_BAUD_RATE 9600
#endif

#if !defined(DOME_DRIVE_SERIAL) && DOME_DRIVE == DOME_DRIVE_SABER
#define DOME_DRIVE_SERIAL Serial0
#endif

#if defined(DOME_DRIVE) && DOME_DRIVE != DOME_DRIVE_SABER && \
    DOME_DRIVE != DOME_DRIVE_PWM && DOME_DRIVE != DOME_DRIVE_ROBOCLAW
#error Unsupported DOME_DRIVE
#endif

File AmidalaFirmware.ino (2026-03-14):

///////////////////////////////////////////////
//
///////////////////////////////////////////////

#define FIRMWARE_NAME F("Amidala RC")
#define VERSION_NUM F("1.3")
#define BUILD_NUM F("1")
#define BUILD_DATE F(__DATE__)

#define DRIVE_SYSTEM_PWM 1
#define DRIVE_SYSTEM_SABER 2
#define DRIVE_SYSTEM_ROBOTEQ_PWM 3
#define DRIVE_SYSTEM_ROBOTEQ_SERIAL 4
#define DRIVE_SYSTEM_ROBOTEQ_PWM_SERIAL 5
// #define DRIVE_SYSTEM         DRIVE_SYSTEM_ROBOTEQ_PWM_SERIAL
#define DRIVE_SYSTEM DRIVE_SYSTEM_ROBOTEQ_PWM

#define DOME_DRIVE_SABER 2
#define DOME_DRIVE_PWM 3

#define DOME_DRIVE DOME_DRIVE_PWM
// #define DOME_DRIVE           DOME_DRIVE_SABER

#define DEFAULT_BAUD_RATE 115200 /*57600*/

#define CONSOLE_BUFFER_SIZE 64

// #define RDH_SERIAL           Serial3
#define RDH_BAUD_RATE 9600

////////////////////////////////

#define MAXIMUM_SPEED 1.0f       // percentage 0.0 - 1.0. default 50%
#define MAXIMUM_GUEST_SPEED 0.5f // percentage 0.0 - 1.0. default 30%
#define DOME_MAXIMUM_SPEED 1.0f  // percentage 0.0 - 1.0. default 100%

// Scale value of 1 means instant. Scale value of 100 means that the throttle
// will increase 1/100 every 25ms
#define ACCELERATION_SCALE 100
// Scale value of 1 means instant. Scale value of 20 means that the throttle
// will decrease 1/20 every 25ms
#define DECELRATION_SCALE 20

#define SCALING                                                                \
  false // set to true if acceleration/decelleration should be applied

#define DEFAULT_DOME_HOME_POSITION 50
#define DEFAULT_DOME_ACCELERATION_SCALE 20
#define DEFAULT_DOME_DECELERATION_SCALE 50
#define DEFAULT_DOME_HOME_MIN_DELAY 6
#define DEFAULT_DOME_HOME_MAX_DELAY 8
#define DEFAULT_DOME_SEEK_MIN_DELAY 6
#define DEFAULT_DOME_SEEK_MAX_DELAY 8
#define DEFAULT_DOME_TARGET_MIN_DELAY 0
#define DEFAULT_DOME_TARGET_MAX_DELAY 1
#define DEFAULT_DOME_SEEK_LEFT 80
#define DEFAULT_DOME_SEEK_RIGHT 80
#define DEFAULT_DOME_FUDGE 2
#define DEFAULT_DOME_SPEED_HOME 40
#define DEFAULT_DOME_SPEED_SEEK 60
#define DEFAULT_DOME_SPEED_TARGET 100
#define DEFAULT_DOME_SPEED_MIN 15
#define DEFAULT_DOME_TIMEOUT 5
#define DEFAULT_DOME_INVERTED false
#define DEFAULT_DOME_MIN_PULSE 1000
#define DEFAULT_DOME_MAX_PULSE 2000

#if DRIVE_SYSTEM == DRIVE_SYSTEM_SABER
#define DRIVE_SERIAL Serial3
#define DOME_DRIVE_SERIAL DRIVE_SERIAL
#define CHANNEL_MIXING                                                         \
  true // set to true premix channels before sending commands
#elif DRIVE_SYSTEM == DRIVE_SYSTEM_PWM
#define CHANNEL_MIXING                                                         \
  false // set to false if motor controller will mix the channels
#elif DRIVE_SYSTEM == DRIVE_SYSTEM_ROBOTEQ_PWM
#define CHANNEL_MIXING                                                         \
  false // set to false if motor controller will mix the channels
#elif DRIVE_SYSTEM == DRIVE_SYSTEM_ROBOTEQ_SERIAL
#define DRIVE_BAUD_RATE 115200
#define CHANNEL_MIXING                                                         \
  false // set to false if motor controller will mix the channels
#elif DRIVE_SYSTEM == DRIVE_SYSTEM_ROBOTEQ_PWM_SERIAL
#define DRIVE_BAUD_RATE 115200
#define CHANNEL_MIXING                                                         \
  false // set to false if motor controller will mix the channels
#else
#error Unsupported DRIVE_SYSTEM
#endif

// #define EXPERIMENTAL_JEVOIS_STEERING

#if !defined(DRIVE_BAUD_RATE) && DOME_DRIVE == DOME_DRIVE_SABER
#define DRIVE_BAUD_RATE 9600
#endif

#if !defined(DOME_DRIVE_SERIAL) && DOME_DRIVE == DOME_DRIVE_SABER
#define DOME_DRIVE_SERIAL Serial3
#endif

#ifndef MARCDUINO_BAUD_RATE
#define MARCDUINO_BAUD_RATE 9600
#endif

#ifndef MAX_GESTURE_LENGTH
#define MAX_GESTURE_LENGTH 8
#endif

#ifndef GESTURE_TIMEOUT_MS
#define GESTURE_TIMEOUT_MS 2000
#endif

#ifndef LONG_PRESS_TIME
#define LONG_PRESS_TIME 3000
#endif

#ifndef MAX_AUX_STRINGS
#define MAX_AUX_STRINGS 40
#endif

////////////////////////////////

#define USE_DEBUG
// #define USE_DOME_SENSOR_SERIAL_DEBUG
// #define USE_POCKET_REMOTE_DEBUG
// #define USE_PPM_DEBUG
// #define USE_MOTOR_DEBUG
// #define USE_DOME_DEBUG
// #define USE_SERVO_DEBUG
// #define USE_VERBOSE_SERVO_DEBUG

////////////////////////////////

#include "ReelTwo.h"
#include "SD.h"
#include "SPI.h"
#if DRIVE_SYSTEM == DRIVE_SYSTEM_PWM
#include "drive/TankDrivePWM.h"
#endif
#if DRIVE_SYSTEM >= DRIVE_SYSTEM_ROBOTEQ_PWM &&                                \
    DRIVE_SYSTEM <= DRIVE_SYSTEM_ROBOTEQ_PWM_SERIAL
#include "drive/TankDriveRoboteq.h"
#endif
#if DOME_DRIVE == DRIVE_SYSTEM_SABER
#include "drive/TankDriveSabertooth.h"
#endif
#if DOME_DRIVE == DOME_DRIVE_PWM
#include "drive/DomeDrivePWM.h"
#elif DOME_DRIVE == DOME_DRIVE_SABER
#include "drive/DomeDriveSabertooth.h"
#endif
#include "ServoDispatchDirect.h"
#include "ServoEasing.h"
#include "core/MedianSampleBuffer.h"
#include <Wire.h>
#include <hcr.h>

////////////////////////////////

// Audio hardware selection
#define AUDIO_HW_HCR    1  // Human Cyborg Relations board (default)
#define AUDIO_HW_VMUSIC 2  // VMusic2

////////////////////////////////

#define SERVO1_PIN 2
#define SERVO2_PIN 3
#define SERVO3_PIN 4
#define SERVO4_PIN 5
#define SERVO5_PIN 6
#define SERVO6_PIN 7
#define SERVO7_PIN 8
#define SERVO8_PIN 9
#define SERVO9_PIN 10
#define SERVO10_PIN 11
#define SERVO11_PIN 12
#define SERVO12_PIN 13

#define DOUT1_PIN 22
#define DOUT2_PIN 23
#define DOUT3_PIN 24
#define DOUT4_PIN 25
#define DOUT5_PIN 26
#define DOUT6_PIN 27
#define DOUT7_PIN 28
#define DOUT8_PIN 29

#define DRIVE_ACTIVE_PIN DOUT7_PIN
#define DOME_ACTIVE_PIN DOUT8_PIN

#define PPMIN_PIN 49

#define ANALOG1_PIN A0
#define ANALOG2_PIN A1

#define RCSEL_PIN 30
#define SEL2_PIN 31

#define STATUS_J1_PIN 32
#define STATUS_J2_PIN 33
#define STATUS_RC_PIN 34
#define STATUS_S1_PIN 35
#define STATUS_S2_PIN 36
#define STATUS_S3_PIN 37
#define STATUS_S4_PIN 38

#define CONSOLE_SERIAL Serial
#define XBEE_SERIAL Serial1
// #define VMUSIC_SERIAL       Serial2
#ifdef VMUSIC_SERIAL
#include <audio/VMusic.h>
#endif
#if !defined(DOME_DRIVE_SERIAL) && !defined(RDH_SERIAL)
#define AUX_SERIAL Serial3
#endif
////////////////////////////////

// I2C bus recovery pin definitions
// On Arduino Mega: SDA = pin 20, SCL = pin 21
#define I2C_SDA_PIN 20
#define I2C_SCL_PIN 21

////////////////////////////////

// Group ID is used by the ServoSequencer and some ServoDispatch functions to
// identify a group of servos.
//
//   Pin  Group ID,      Min,  Max
const ServoSettings servoSettings[] PROGMEM = {
    {SERVO1_PIN, 1000, 2000, 0},  {SERVO2_PIN, 1000, 2000, 0},
    {SERVO3_PIN, 1000, 2000, 0},  {SERVO4_PIN, 1000, 2000, 0},
    {SERVO5_PIN, 1000, 2000, 0},  {SERVO6_PIN, 1000, 2000, 0},
    {SERVO7_PIN, 1000, 2000, 0},  {SERVO8_PIN, 1000, 2000, 0},
    {SERVO9_PIN, 1000, 2000, 0},  {SERVO10_PIN, 1000, 2000, 0},
    {SERVO11_PIN, 1000, 2000, 0}, {SERVO12_PIN, 1000, 2000, 0}};

ServoDispatchDirect<SizeOfArray(servoSettings)> servoDispatch(servoSettings);

////////////////////////////////

class Gesture {
public:
  Gesture(const char *gestureStr = nullptr) { setGesture(gestureStr); }

  bool isEmpty() { return fGesture == 0; }

  uint8_t getGestureType(char ch) {
    switch (ch) {
    case '1':
    case '2':
    case '3':
    case '4':
    case '5':
    case '6':
    case '7':
    case '8':
    case '9':
      return ch - '0';
    case 'A':
      return 10;
    case 'B':
      return 11;
    case 'C':
      return 12;
    case 'D':
      return 13;
    default:
      return 0;
    }
  }

  bool matches(const char *str) {
    if (fGesture == 0 && *str == '\0')
      return true;
    if (fGesture == 0)
      return false;
    const char *s = str;
    unsigned cnt = 0;
    uint32_t quotient = fGesture;
    while (quotient != 0 && cnt < MAX_GESTURE_LENGTH) {
      uint8_t val[] = {'\0', '1', '2', '3', '4', '5', '6',
                       '7',  '8', '9', 'A', 'B', 'C', 'D'};
      uint32_t remainder = quotient % 14;
      if (*s++ != val[remainder])
        return false;
      quotient = quotient / 14;
    }
    return (*s == '\0');
  }

  char *getGestureString(char *str) {
    char *s = str;
    unsigned cnt = 0;
    uint32_t quotient = fGesture;
    while (quotient != 0 && cnt < MAX_GESTURE_LENGTH) {
      uint8_t val[] = {'\0', '1', '2', '3', '4', '5', '6',
                       '7',  '8', '9', 'A', 'B', 'C', 'D'};
      uint32_t remainder = quotient % 14;
      *s++ = val[remainder];
      *s = '\0';
      quotient = quotient / 14;
    }
    return str;
  }

  void setGesture(const char *str) {
    fGesture = 0;
    const char *strend = str + strlen(str);
    while (str != strend) {
      // Base 16
      fGesture = fGesture * 14 + getGestureType(*--strend);
    }
  }

private:
  uint32_t fGesture;
};

////////////////////////////////

#include <EEPROM.h>
#include <XBee.h>

class PPMDecoder {
public:
  PPMDecoder(uint8_t pin, unsigned channelCount)
      : fPin(pin), fChannelCount(channelCount),
        fChannel(new uint16_t[fChannelCount]),
        fLastChannel(new uint16_t[fChannelCount]) {
    init();
  }

  ~PPMDecoder() {
    delete[] fChannel;
    delete[] fLastChannel;
  }

  void init() {
    fPass = 0;
    fPinState = LOW;
    fCurrent = fChannelCount;
    memset(fChannel, '\0', sizeof(fChannelCount) * sizeof(uint16_t));
    memset(fLastChannel, '\0', sizeof(fChannelCount) * sizeof(uint16_t));
  }

  bool decode() {
    uint32_t pulse = readPulse(PPMIN_PIN);
    if (!pulse)
      return false;
    if (fCurrent == fChannelCount) {
      if (pulse > 3000)
        fCurrent = 0;
    } else {
      fChannel[fCurrent++] = pulse;
      if (fCurrent == fChannelCount) {
        for (unsigned i = 0; i < fChannelCount; i++) {
          if (fChannel[i] > 2000 || fChannel[i] < 100) {
            fChannel[i] = fLastChannel[i];
          } else {
            fChannel[i] = (fLastChannel[i] + fChannel[i]) / 2;
            fPass++;
          }
        }
        if (fPass > 10) {
          for (unsigned i = 0; i < fChannelCount; i++) {
#ifdef USE_PPM_DEBUG
            DEBUG_PRINT("CH");
            DEBUG_PRINT(i + 1);
            DEBUG_PRINT.print(": ");
            DEBUG_PRINT(fChannel[i]);
            DEBUG_PRINT(" ");
#endif
            fLastChannel[i] = fChannel[i];
          }
#ifdef USE_PPM_DEBUG
          DEBUG_PRINT('\r');
#endif
          fPass = 0;
          return true;
        }
      }
    }
    return false;
  }

  uint16_t channel(unsigned ch, unsigned minvalue, unsigned maxvalue,
                   unsigned neutralvalue) {
    uint16_t pulse = (ch < fChannelCount) ? fChannel[ch] : 0;
    if (pulse != 0)
      return map(max(min(pulse, 1600), 600), 600, 1600, minvalue, maxvalue);
    return neutralvalue;
  }

private:
  uint8_t fPin;
  int fPinState;
  unsigned fPass;
  unsigned fCurrent;
  unsigned fChannelCount;
  uint32_t fRisingTime;
  uint16_t *fChannel;
  uint16_t *fLastChannel;

  uint32_t readPulse(uint8_t pin) {
    uint8_t state = digitalRead(pin);
    uint32_t pulseLength = 0;

    // On rising edge: record current time.
    if (fPinState == LOW && state == HIGH) {
      fRisingTime = micros();
    }

    // On falling edge: report pulse length.
    if (fPinState == HIGH && state == LOW) {
      unsigned long fallingTime = micros();
      pulseLength = fallingTime - fRisingTime;
    }

    fPinState = state;
    return pulseLength;
  }
};

////////////////////////////////

class AmidalaController;

////////////////////////////////

struct ButtonAction {
  enum {
    kNone = 0,
    kSound = 1,
    kServo = 2,
    kDigitalOut = 3,
    kI2CCmd = 4,
    kAuxStr = 5,
    kI2CStr   = 6,
    kHCREmote = 7,  // Trigger an HCR emotion (emotion, level)
    kHCRMuse  = 8   // Toggle HCR musing on/off
  };
  uint8_t action;
  union {
    struct {
      uint8_t soundbank;
      uint8_t sound;
      uint8_t auxstring;
    } sound;
    struct {
      uint8_t num;
      uint8_t pos;
      uint8_t auxstring;
    } servo;
    struct {
      uint8_t num;
      uint8_t state;
      uint8_t auxstring;
    } dout;
    struct {
      uint8_t target;
      uint8_t cmd;
      uint8_t auxstring;
    } i2ccmd;
    struct {
      uint8_t unused1;
      uint8_t unused2;
      uint8_t auxstring;
    } aux;
    struct {
      uint8_t target;
      uint8_t cmd;
      uint8_t auxstring;
    } i2cstr;
    struct {
      uint8_t emotion;   // HAPPY=0, SAD=1, MAD=2, SCARED=3, OVERLOAD=4
      uint8_t level;     // EMOTE_MODERATE=0, EMOTE_STRONG=1
      uint8_t auxstring;
    } emote;
  };

  void printDescription(Print *stream) {
    switch (action) {
    case kNone:
      break;
    case kSound:
      stream->print(F("Sound Bank #"));
      stream->print(sound.soundbank);
      if (sound.sound != 0) {
        stream->print(F(","));
        stream->print(sound.sound);
      }
      break;
    case kServo:
      stream->print(F("Servo #"));
      stream->print(servo.num);
      stream->print(F(", On Pos="));
      stream->print(servo.pos);
      break;
    case kDigitalOut:
      stream->print(F("DOut #"));
      stream->print(dout.num);
      stream->print(F(", Type="));
      switch (dout.state) {
      case 0:
        stream->print(F("NO"));
        break;
      case 1:
        stream->print(F("NC"));
        break;
      case 2:
        stream->print(F("MON"));
        break;
      }
      break;
    case kI2CCmd:
      stream->print(F("i2c Dest #"));
      stream->print(i2ccmd.target);
      stream->print(F(", Cmd="));
      stream->print(i2ccmd.cmd);
      break;
    case kAuxStr:
      stream->print(F("Aux #"));
      stream->print(aux.auxstring);
      break;
    case kI2CStr:
      stream->print(F("i2c Aux Output #"));
      stream->print(i2cstr.cmd);
      stream->print(F(", Dest "));
      stream->print(i2cstr.target);
      break;
    case kHCREmote:
      stream->print(F("HCR "));
      switch (emote.emotion) {
        case HAPPY:    stream->print(F("Happy"));   break;
        case SAD:      stream->print(F("Sad"));     break;
        case MAD:      stream->print(F("Mad"));     break;
        case SCARED:   stream->print(F("Scared"));  break;
        case OVERLOAD: stream->print(F("Overload")); break;
        default:       stream->print(emote.emotion); break;
      }
      if (emote.emotion != OVERLOAD)
        stream->print(emote.level ? F(" Strong") : F(" Moderate"));
      break;
    case kHCRMuse:
      stream->print(F("HCR Muse Toggle"));
      break;
    }
    if (action != kAuxStr && action != kHCREmote && action != kHCRMuse &&
        aux.auxstring != 0) {
      stream->print(F(", Aux #"));
      stream->print(aux.auxstring);
    }
    stream->println();
  }
};

struct GestureAction {
  Gesture gesture;
  ButtonAction action;

  void printDescription(Print *stream) {
    char buf[MAX_GESTURE_LENGTH + 1];
    if (!gesture.isEmpty()) {
      stream->print(gesture.getGestureString(buf));
      stream->print(F(": "));
      action.printDescription(stream);
    }
  }
};

struct AuxString {
  char str[32];
};

////////////////////////////////

class AmidalaConsole : public Print {
public:
  AmidalaConsole() : fPos(0) {}
  virtual ~AmidalaConsole() {}

  void init(AmidalaController *controller);
  void process();
  bool processConfig(const char *cmd);
  void processCommand(const char *cmd);
  bool process(char ch, bool config = false);

  void processGesture(const char *gesture);
  void process(ButtonAction &button);
  void processButton(unsigned num);
  void processLongButton(unsigned num);

  virtual size_t write(uint8_t ch) { return write(&ch, 1); }

  virtual size_t write(const uint8_t *buffer, size_t size) override {
    if (fPrompt) {
      CONSOLE_SERIAL.println();
      fPrompt = false;
    }
    return CONSOLE_SERIAL.write(buffer, size);
  }

  void printNum(unsigned num, unsigned width = 4) {
    char buf[16];
    snprintf(buf, sizeof(buf), "%d", num);
    for (size_t len = strlen(buf); len < width;) {
      buf[len++] = ' ';
      buf[len] = '\0';
    }
    print(buf);
  }

  void printServoPos(uint16_t num) {
    if (servoDispatch.isActive(num)) {
      printNum(servoDispatch.currentPos(num));
    } else {
      print("----");
    }
  }

  void randomToggle();
  void setVolumeNoResponse(uint8_t volume);
  void playSound(int sndbank, int snd = 0);
  void setServo();
  void setDigitalOut();
  void outputString();
  void showXBEE();
  void printVersion();
  void printHelp();
  void showLoadEEPROM(bool load = false);
  void showCurrentConfiguration();
  void writeCurrentConfiguration();
  void monitorToggle();
  void monitorOutput();
  void setMinimal(bool minimal) { fMinimal = minimal; }

private:
  AmidalaController *fController = nullptr;
  unsigned fPos;
  char fBuffer[CONSOLE_BUFFER_SIZE];
  bool fMonitor = false;
  bool fPrompt = false;
  bool fMinimal = true;
};

class ServoPD {
public:
  ServoPD(long Kp, long Kd, long zero, long range, long scalebits = 8)
      : fKp(Kp), fKd(Kd), fPos(zero << scalebits),
        fPrevTarget(zero << scalebits), fZero(zero << scalebits),
        fRange(range << scalebits), fScaleBits(scalebits) {}

  // void attach(int pin, int pos)
  // {
  //     // itsServo.attach(pin);
  //     itsPos = (pos << itsScaleBits);
  //     // itsServo.write(pos);
  // }

  long get() const { return (fPos >> fScaleBits); }

  void update(long targetpos) {
    targetpos <<= fScaleBits;
    long diff = fKp * targetpos + fKd * (targetpos - fPrevTarget);
    fPos += (diff >> 16);
    fPos = constrain(fPos, fZero - fRange, fZero + fRange);
    // fServo.write(fPos >> fScaleBits);
    fPrevTarget = targetpos;
  }

  void reset(long targetpos) {
    targetpos <<= fScaleBits;
    fPos = constrain(fPos, fZero - fRange, fZero + fRange);
    fPrevTarget = targetpos;
  }

  long rawget() { return fPos >> fScaleBits; }

  void rawset(long rawval) {
    fPos = rawval << fScaleBits;
    // fServo.write(rawval);
  }

private:
  long fKp, fKd, fPos, fPrevTarget, fZero, fRange, fScaleBits;
};

// Pan and tilt servos zero values and +/- angular range, in degrees:
#define PANZERO 90
#define PANRANGE 60
#define TILTZERO 70
#define TILTRANGE 40

// Create one servo PD controler for camera pan and another for camera tilt:
ServoPD panservo(400, 200, PANZERO, PANRANGE);
ServoPD tiltservo(300, 100, TILTZERO, TILTRANGE);

////////////////////////////////

#ifdef EXPERIMENTAL_JEVOIS_STEERING

class JevoisConsole {
public:
  JevoisConsole() : fSteering(300) {}
  virtual ~JevoisConsole() {}

  void init(AmidalaController *controller);

  void processCommand(char *cmd = nullptr) {
    int id, targx, targy, targw, targh;
    char *tok = (cmd != nullptr) ? strtok(cmd, " \r") : nullptr;
    int state = 0;

    while (tok) {
      // State machine:
      // 0: start parsing
      // 1: N2 command, parse id
      // 2: N2 command, parse targx
      // 3: N2 command, parse targy
      // 4: N2 command, parse targw
      // 5: N2 command, parse targh
      // 6: N2 command complete
      // 1000: unknown command
      switch (state) {
      case 0:
        state = (strcmp(tok, "N2") == 0) ? 1 : 1000;
        break;
      case 1:
        id = atoi(&tok[1]);
        state = 2;
        break;
      case 2:
        targx = atoi(tok);
        state = 3;
        break;
      case 3:
        targy = atoi(tok);
        state = 4;
        break;
      case 4:
        targw = atoi(tok);
        state = 5;
        break;
      case 5:
        targh = atoi(tok);
        state = 6;
        break;
      default:
        break;
      }
      tok = strtok(0, " \r\n");
    }

    // If a complete new N2 command was received, act:
    if (state == 6) {
      // panservo.update(-targx);
      tiltservo.update(targy);

      fSteering.setCurrentDistance(targw);
      // fSteering.setCurrentAngle(panservo.get() - PANZERO);
      fSteering.setCurrentAngle(targx);

      // CONSOLE_SERIAL.print("[");
      // CONSOLE_SERIAL.print(fSteering.getThrottle());
      // CONSOLE_SERIAL.print(",");
      // CONSOLE_SERIAL.print(fSteering.getTurning());
      // CONSOLE_SERIAL.print(","); CONSOLE_SERIAL.print(targx);
      // CONSOLE_SERIAL.println("]");
    } else {
      // Slow down if we lost track:
      fSteering.lost();
    }
  }

  void process() {
    while (AUX_SERIAL.available()) {
      int ch = AUX_SERIAL.read();
      if (ch == '\n') {
        fBuffer[fPos] = '\0';
        fPos = 0;
        if (*fBuffer != '\0') {
          processCommand(fBuffer);
        }
      } else if (fPos < SizeOfArray(fBuffer) - 1) {
        fBuffer[fPos++] = ch;
      }
      fLastTime = millis();
    }
    if (fLastTime + 50 < millis()) {
      processCommand();
      fLastTime = millis();
    }
  }

private:
  AmidalaController *fController = nullptr;
  TargetSteering fSteering;
  char fBuffer[128];
  unsigned fPos = 0;
  uint32_t fLastTime;
};
#endif

////////////////////////////////
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
void loop() { AnimatedEvent::process(); }

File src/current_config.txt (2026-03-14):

#START
# --- XBEE Configuration ---
# Unique serial numbers for the XBEE modules (Lower 32-bits in Hex)
xbr=40C8CCB0
xbl=40C8CCC4

# --- Joystick Analog Calibration ---
# Reference voltages for analog stick limits (0-1024)
rvrmin=0
rvrmax=1014
rvlmin=0
rvlmax=1014
# Vertical and Horizontal offset adjustments for Joystick 1 (0-80)
j1adjv=0
j1adjh=0

# --- RC Radio Configuration ---
# Number of RC channels (6-8)
rcchn=6
# Deadzone (1-50): Ignores small stick movements
rcd=30
# Jitter/Hysteresis (1-40): Smooths signal noise
rcj=5
# Failsafe Timeout (ms): Time before motors stop if signal is lost
fst=1000
# Global Servo Pulse Limits (µs)
minpulse=1000
maxpulse=2000

# --- Audio Hardware ---
# audiohw: hcr=Human Cyborg Relations board (default), vmusic=VMusic2
audiohw=hcr
# Startup emote emotion: 0=Happy, 1=Sad, 2=Mad, 3=Scared, 4=Overload
startupem=0
# Startup emote level: 0=Moderate, 1=Strong
startuplvl=0
# Acknowledge emote emotion (same scale as startupem)
ackem=0
# Acknowledge emote level (same scale as startuplvl)
acklvl=0

# --- General System Settings ---
# Global Volume (0-100)
volume=50
# Startup Sound: Play a sound when the robot boots (y/n)
startup=y
# Random Sounds: Start in random sound mode on boot (y/n)
rndon=n
# Acknowledge Sounds: Sound response to commands (y/n)
ackon=n
# Acknowledge Type: g=general, a=auto, d=dome, s=speed, r=radio
acktype=a
# Slow Mode: Start in slow mode for safer driving (y/n)
goslow=n
# Channel Mixing: Mix channels 1 & 2 for tank drive (y/n)
mix12=n
# Autocorrect: Enable signal error correction (y/n)
auto=n

# --- Random Sound Timing (Seconds) ---
mindelay=20
maxdelay=45

# --- Communication & I2C ---
# This board's I2C address (0 = Master)
myi2c=0
# Aux Serial Port Baud Rate
auxbaud=9600
# ASCII code for delimiter (default 58 = ':', 124 = '|')
auxdelim=124
# ASCII code for EOL (default 13 = Carriage Return)
auxeol=13

# --- Dome Motor Control ---
# Default Dome Mode: 0=Manual, 1=Auto-Home, 2=Random, 3=Seek
domemode=0
# Maximum Dome Speed (0-100)
domespeed=100
# Dome Home position in degrees (0-360)
domehome=50
# Dome rotation inversion (y/n)
domeflip=n
# Dome Fudge Factor: Accuracy tolerance for sensors (1-20)
domefudge=2
# Speed during homing and seeking (1-100)
domespeedhome=40
domespeedseek=60
# Delays between movements (Seconds)
domehomemin=6
domehomemax=8
domeseekmin=6
domeseekmax=8
# Rotation range for seeking (Degrees)
domeseekl=80
domeseekr=80
# Enable Dome Control on RC Channel 6 (y/n)
domech6=n

# --- Gestures for Special Toggles ---
# These set which stick gesture string toggles which mode (default values)
rnd=3
ackgest=252
# slowgest=858
domegest=

# --- Servo Channel Configuration ---
# Format: s=NN,min,max,neutral,deadzone,trim,speed,reversed
# speed: 1 (Slowest) to 100 (Full Acceleration)
s=1,0,180,90,4,0,50,0
s=2,0,180,90,4,0,50,0
s=3,0,180,90,4,0,50,0
s=4,50,130,90,4,0,50,1
s=5,0,180,90,10,0,50,0
s=6,0,180,90,10,0,50,0

# --- Sound Bank Configuration ---
# Format: sb=dir,numfiles
sb=gen,16
sb=chat,22
sb=sad,11
sb=raspb,1
sb=whis,12
sb=scream,4
sb=warn,2
sb=short,1
sb=leia,1
sb=vader,1
sb=sw,1
sb=dance,2
sb=cant,1
sb=leial,1

# --- Aux String Definitions ---
# Format: a=string_here
# One indexed and read in the order they appear

# 1: Sad (Moderate)
a=<SS0>
# 2: Scared (Moderate)
a=<SC0>
# 3: Mad (Moderate)
a=<SM0>
# 4: Very Mad (Strong)
a=<SM1>
# 5: Very Happy (Strong)
a=<SH1>
# 6: Overload
a=<SE>
# 7: Toggle Mute
a=BD:VOL
# 8: Vader
a=BD:VADER
# 9: Utility Arms
a=BD:UARMS
# 10: Toggle Musing
a=BD:MUSE
# 11: Reset All
a=DM:RESET
# 12: Pie Panels
a=DM:PIES
# 13: Low Panels
a=DM:LOW
# 14: All Panels
a=DM:OPENALL
# 15: Leia Sequence
a=DM:LEIA
# 16: Heart Sequence
a=DM:HEART
# 17: Hello There
a=DM:HELLO
# 18: Scream
a=DM:SCREAM
# 19: Panel flutter
a=DM:FLUTTER
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

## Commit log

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2026-03-14 Integrates the human cyborg relations board as the default audio option
    This adds native support for the HCR board, fully swapping out all the native audio controls when the HCR board is selected.
    [current_config.txt]
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2026-03-20 refactor: extract PPMDecoder to ppm_decoder.h
    Moves PPMDecoder out of AmidalaFirmware.ino into include/ppm_decoder.h.
    Updates test_ppm_channel to include the header and adds 5 direct class
    tests (construction, decode with no signal, channel neutral, out-of-range
    channel, init reset). Adds digitalRead/micros stubs to arduino_mock.h
    and switches min/max to macros to match Arduino.h's mixed-type behaviour.
    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
    [AmidalaFirmware.ino, ppm_decoder.h]
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2026-03-20 refactor: extract I2C helpers to i2c_utils.h
    Moves recoverI2CBus(), sendI2CCmd(), sendI2CStr() out of AmidalaController
    into include/i2c_utils.h as free inline functions. Updates the three call
    sites to drop the AmidalaController:: prefix. Adds 10 Unity tests covering
    success/error return codes for both send functions and smoke-tests for
    recoverI2CBus(). Adds Wire mock, pinMode/digitalWrite/delay stubs, and
    INPUT_PULLUP/OUTPUT constants to arduino_mock.h.
    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
    [AmidalaFirmware.ino, i2c_utils.h]
2026-03-20 refactor: extract XBeePocketRemote/DriveController/DomeController to xbee_remote.h
    Moves the three classes out of AmidalaController into include/xbee_remote.h.
    XBeePocketRemote is fully defined in the header. DriveController and
    DomeController declare their virtual methods in the header; the bodies that
    call AmidalaController are defined in the .ino after AmidalaController is
    fully defined (same pattern as JevoisConsole::init). Adds friend declarations
    for DriveController and DomeController to AmidalaController. Adds millis()
    stub to arduino_mock.h. 19 Unity tests cover XBeePocketRemote state mapping,
    button events, failsafe flag, and DriveController/DomeController construction.
    Zero binary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
    [AmidalaFirmware.ino, xbee_remote.h]
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2026-03-22 refactor: move DriveController/DomeController methods to src/drive_controllers.cpp
    Extracts ~165 lines from AmidalaFirmware.ino into a separate translation
    unit. hcrDelayedInit stays in AmidalaFirmware.ino — it initialises the HCR
    audio system and is unrelated to the drive/dome controllers.
    Also fixes a latent ODR violation in amidala_core.h: 13 free functions
    defined in the header without inline were silently allowed when only one
    TU included them, but caused multiple-definition linker errors once a
    second TU included amidala_controller.h. All affected functions now inline.
    ServoDispatchDirect.h and ServoEasing.h moved back to AmidalaFirmware.ino
    (the only TU that uses servoDispatch) to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
    [AmidalaFirmware.ino]
2026-03-22 refactor: move button/gesture dispatch to src/amidala_buttons.cpp
    Extract the four input-to-action methods from AmidalaFirmware.ino into a
    dedicated translation unit:
    AmidalaConsole::process(ButtonAction&)
    AmidalaConsole::processGesture()
    AmidalaConsole::processButton()
    AmidalaConsole::processLongButton()
    No logic changes — audio actions already delegate to fController->fAudio.*
    from the PR 2c refactor. All needed types resolve through the single
    #include "amidala_controller.h".
    Also update REFACTORING.md: revise PR 2c description to reflect the
    AmidalaAudio class introduced in that PR, and mark PR 2d complete.
    All 249 native tests passing.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
    [AmidalaFirmware.ino, amidala_buttons.cpp]
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2026-03-22 refactor: move AmidalaConsole methods to src/amidala_console.cpp
    Move all remaining AmidalaConsole:: method bodies out of AmidalaFirmware.ino
    into src/amidala_console.cpp: write(), init(), setDigitalOut(), outputString(),
    showXBEE(), printVersion(), printHelp(), monitorOutput(), monitorToggle(),
    processCommand(), process(char,bool), and process().
    The file-scope isdigit(const char*, int) and atoi(const char*, int) helpers
    move with processCommand() and are marked static to preserve internal linkage
    and avoid shadowing the standard library overloads in other TUs.
    All 249 native tests pass.
    [AmidalaFirmware.ino, amidala_console.cpp]
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2026-03-22 fix: code review — bugs, stale comments, and test coverage gaps
    Bugs fixed:
    - config.cpp: rvrmax=/rvlmin=/rvlmax= all wrote to params.rvrmin (copy-paste)
    - config.cpp: servo pos clamp min(max(pos,180),90) always produced 90 → min(max(pos,0),180)
    - buttons.cpp: processButton/processLongButton guard num<count didn't check num>=1 (unsigned underflow at num==0)
    - ppm_decoder.h: memset used sizeof(fChannelCount) instead of fChannelCount*sizeof(uint16_t) (zeroed 4 bytes instead of N*2)
    - ppm_decoder.h: DEBUG_PRINT.print(": ") malformed macro call → DEBUG_PRINT(": ")
    - jevois_console.h: fLastTime and fPos uninitialized in constructor
    - params.h: sRAMInited was checked but never set to true (d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
    [AmidalaFirmware.ino, audio.h, button_actions.h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]
2026-03-22 Fix a few build issues
    this ensures the build is green and tests succeed.
    [controller.cpp, controller.h, globals.cpp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]
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2026-03-27 Rename: serial is primary output, I2C is auxiliary
    Serial3 (COM3) was called "auxiliary serial" throughout the codebase.
    I2C output was implicitly treated as the primary alternative. This
    inverts that framing — serial is now the primary downstream output
    and I2C is the auxiliary/backup path.
    Renames across headers, source, tests, config, and docs:
    - AUX_SERIAL → SERIAL (pin_config.h macro)
    - AuxString → SerialString, kAuxStr → kSerialStr
    - aux union struct → serial, auxstring field → serialstr
    - sendAuxString() → sendSerialString()
    - getAuxStringCount() → getSerialStringCount()
    - MAX_AUX_STRINGS → MAX_SERIAL_STRINGS
    - params: auxbaud/delim/eol/init/acount/A[] →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
    [current_config.txt]
2026-04-05 Add RoboClaw closed-loop dome drive with encoder homing and calibration
    Integrates a new DomeDriveRoboClaw class that drives an encoder motor
    via RoboClaw packet serial, uses a hall-effect sensor for automatic
    homing on boot, and persists a 10-revolution calibration ratio to EEPROM.
    Supports joystick control, absolute/relative angle commands, random wander
    mode, and stall/obstruction detection with manual-reset lockout.
    State machine decision logic (homing, calibration, obstruction) and EEPROM
    persistence are extracted as pure free functions in dome_position_math.h,
    making the core logic fully unit-testable without hardware. Adds 96 new
    tests across test_dome_drive_roboclaw, test_params, te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
    [config.cpp, console.cpp, controller.cpp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]
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2026-04-12 Add DomeCmd button/gesture action for RoboClaw dome control
    Introduces kDomeCmd (action=9) to the button and gesture config system,
    giving full dome drive control from controller buttons without console access.
    New DomeCmdType subcmds (0–7): RandomToggle, Stop, Front, Home, Calibrate,
    GotoAbs, RelativePos, RelativeNeg. Config format: b=N,9,subcmd[,angle[,serialstr]]
    with the same syntax for lb= (long-press) and g= (gesture) mappings.
    Also fixes three pre-existing build errors exposed when DOME_DRIVE_ROBOCLAW is
    active: motor() override missing from DomeDriveRoboClaw header; controller.h
    not including drive_config.h before the DOME_DRIVE conditional includes;
    DomePosition setter method na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
    [current_config.txt]
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2026-04-12 Fix RoboClaw dome drive hardware bring-up issues
    Three bugs found during first hardware test of the dome drive:
    1. Homing and calibration silently stalled without a joystick connected.
    DomeDrive::animate() only consumes autonomousDriveDome() when a
    joystick controller reports isConnected(). Replace the
    autonomousDriveDome() calls in handleHoming() and handleCalibrating()
    with direct sendMotorCommand() calls so the motor runs regardless of
    controller state.
    2. `dome=` console commands always returned "Invalid". The routing in
    processCommand() used startswith(), which advances the pointer past
    the prefix as a side effect, so the subsequent `cmd + 5` offset
    skipped 5 b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
    [current_config.txt]
2026-04-12 Fix homing/calibration fighting joystick when controller is connected
    When a joystick is connected, DomeDrive::animate() → domeStick() sees
    idle stick input (m=0) and calls motor(0), cancelling the homing or
    calibration sweep command every 25ms cycle.
    Remove the DomeDrive::animate() calls from the kHomingContinue and
    kStateCalibrating paths. Joystick input is intentionally ignored during
    these autonomous operations; it resumes normally once kStateHomed is
    reached.
    [dome_drive_roboclaw.cpp]
2026-04-12 Fix dome wobbling at target position in random/auto mode
    Root cause: two interacting issues caused the dome to oscillate:
    1. DEFAULT_DOME_FUDGE was 2° — the motor minimum-speed floor meant the
    dome always arrived at ≥15% QPPS (~40°/sec), crossing the 2° dead
    zone in ~50ms and reliably overshooting on every cycle.
    2. DEFAULT_DOME_SPEED_MIN was 15 (hardcoded, not configurable) — the
    minimum speed floor in DomeDrive::getSpeed() prevented the motor from
    creeping slowly near the target regardless of how small the error was.
    Fix:
    - Raise DEFAULT_DOME_FUDGE from 2 to 10 degrees.
    - Lower DEFAULT_DOME_SPEED_MIN from 15 to 5.
    - Add domespeedmin as a runtime-configurable param (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
    [current_config.txt]
2026-04-12 Fix absolute-stick mode: dome unresponsive after enabling
    DomeDrive::domeStick() gates ALL motor commands (including DomePosition
    kTarget processing) behind `abs(m) != 0 || fAutoDrive != 0`.
    kStateAbsoluteStick was zeroing the stick and routing through
    DomeDrive::animate(), so with m=0 and fAutoDrive=0 the entire motor
    block was skipped — the dome sat silent.
    Switch kStateAbsoluteStick to the same direct pattern used by homing
    and calibration: implement a proportional closed-loop in
    handleAbsoluteStick() that calls sendMotorCommand() directly and
    returns early, bypassing DomeDrive::animate() entirely.
    Extract the speed-from-error formula into dome_abs_stick_speed() in
    dome_position_math.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
    [dome_drive_roboclaw.cpp, dome_drive_roboclaw.h, dome_position_math.h]
2026-04-12 Fix abs-stick: negate ly to match JoystickController axis convention
    JoystickController reports ly positive = stick pushed toward the user
    (back/down), not forward. Negate ly when calling dome_stick_to_angle()
    so that physical forward = 0°, right = 90°, back = 180°, left = 270°.
    Update dome_stick_to_angle() doc comment and the forward/back unit
    tests to reflect the actual hardware axis polarity.
    [dome_drive_roboclaw.cpp, dome_position_math.h]
2026-04-12 fix: toggle behavior simplification
    This fixes some toggle behavior that was duplicating code, and or just did not toggle. It also adds some todos for the next session.
    [controller.cpp, dome_drive_roboclaw.cpp, dome_drive_roboclaw.h]
2026-04-13 Fix dome direction: wire domeflip to setInverted(), default to true
    params.domeflip was parsed from config but never applied to
    DomeDrive::setInverted() — the code always used DEFAULT_DOME_INVERTED
    (false), so the dome always moved in the wrong direction.
    - controller.cpp: use params.domeflip instead of DEFAULT_DOME_INVERTED
    - config.cpp: give domeflip= its own handler with a live-update call to
    setInverted() so changing the setting takes effect without a reflash
    - drive_config.h: DEFAULT_DOME_INVERTED = true (correct motor direction
    for this build is inverted; domeflip=n in config means "use default")
    - current_config.txt: domeflip=n (explicit no-op, matches new default)
    - test_drive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
    [config.cpp, controller.cpp, drive_config.h]
2026-04-13 Resolve TODO items: random mode, decel curve, drive indicators, dome refactor
    - dome_abs_stick_speed(): cruise-then-decelerate control curve (full speed
    until within decelZone of target, then linear ramp to speedMin); tests updated
    - handleRandomMode(): implement random wander; cache seek params in
    applyDomePositionParams(); add kStateRandom routing in animate();
    fix enableRandomMode() to set up state correctly
    - sendMotorCommand(): move fLastCommandedSpeed assignment here so all callers
    (autonomous modes that bypass motor()) also update it for obstruction detection;
    add getLastCommandedSpeed() public accessor
    - Controller indicators: guard drive indicator (pin 7) with
    #if DRI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
    [controller.cpp, controller.h, dome_drive_roboclaw.cpp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]
2026-04-13 Fix three bugs found in post-merge review
    - readEncoder(): remove dead-code ternary (both branches returned the same
    value; simplify to a plain return)
    - handleAbsoluteStick(): remove stale TODO comment (decel curve was already
    fixed in the previous commit)
    - executeDomeAction(): change arg from uint8_t to int so console commands
    dome=270 and dome=+300 are not silently truncated to 14° and 44°; button
    path still passes uint8_t which widens to int without truncation
    [controller.cpp, controller.h, dome_drive_roboclaw.cpp]
2026-04-13 Extract driveClosedLoop() helper; fix wrong doc comment
    handleAbsoluteStick() and handleRandomMode() shared an identical
    4-line block: angular-error → abs-stick-speed → sendMotorCommand →
    checkObstruction. Extract it to driveClosedLoop(targetDegrees) → bool
    so each caller states intent clearly and the arithmetic lives in one place.
    The bool return (true = within fudge zone) lets handleRandomMode() drop
    its duplicate arrival check.
    Also fix copy-paste error in the disableRandomMode() doc comment which
    said "Leave absolute-stick mode" instead of "Leave random wander mode".
    [dome_drive_roboclaw.cpp, dome_drive_roboclaw.h]
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2026-04-14 docs: document long-press button feature (3-second threshold, lb= format)
    Add a clear explanation of short-press vs long-press semantics to both
    README.md and the current_config.txt header comment, including the
    3-second hold time and the lb= format with practical examples.
    [current_config.txt]
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2026-04-19 Add dome sequence pause to suppress auto behaviors during animations
    External controllers (body/dome boards) can now send `dome=seqon[,<sec>]`
    over serial to suspend autonomous dome behaviors — random wander
    (kStateRandom) and DomePosition auto modes — while an animation sequence
    plays, and `dome=seqoff` to clear the pause. A watchdog auto-clears the
    pause after the specified duration (default 30s, capped at 5 min) so the
    dome recovers if the caller crashes mid-sequence.
    Homing, calibration, explicit positional commands, and joystick input
    are intentionally not suppressed. On initial activation the motor is
    zeroed once so it doesn't coast on its last random speed; subsequent
    refresh cal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
    [controller.cpp, dome_drive_roboclaw.cpp, dome_drive_roboclaw.h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]
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2026-04-21 Fix goToAngle/goToRelative to bypass broken ReelTwo path
    The old implementation delegated to DomeDrive::domeStick() via
    DomePosition::kTarget mode. This had three bugs:
    1. domeStick() only runs when a joystick is connected, so programmatic
    moves silently did nothing without a controller plugged in.
    2. kTarget mode has a built-in 6-second idle delay (getDomeTargetMinDelay
    defaults to 6 s) before commanding the motor — we never configured it.
    3. DomeDrive::moveDomeToTarget() uses the opposite sign convention from
    our encoder, driving the dome away from its target.
    Replace with a new kStateGoToAngle state that calls driveClosedLoop()
    directly — the same path already used by handle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
    [dome_drive_roboclaw.cpp, dome_drive_roboclaw.h]
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2026-04-21 Remove DomeDrive inheritance — roboclaw dome drive is now self-contained
    DomeDriveRoboClaw now inherits only AnimatedEvent + SetupEvent (the ReelTwo
    event-loop hooks) and has zero dependency on DomeDrive or any ReelTwo drive
    class. All dome movement logic — joystick drive, homing, calibration,
    go-to-angle, random wander, absolute-stick — lives entirely in this class.
    Changes:
    - Inherit SetupEvent + AnimatedEvent instead of DomeDrive
    - Replace DomeDrive::animate() call with new driveFromJoystick(), which
    implements the same joystick path (deadband, power curve, L2/R2 trigger
    boost, invert flag) without any DomeDrive machinery
    - Move fDomeStick, fMaxSpeed, fUseLeftStick, fInverted,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
    [config.cpp, dome_drive_roboclaw.cpp, dome_drive_roboclaw.h]
2026-04-21 Remove SetupEvent/AnimatedEvent — dome drive is now a plain object
    DomeDriveRoboClaw no longer inherits SetupEvent or AnimatedEvent. setup()
    and animate() are now called explicitly by AmidalaController, which is
    already in the ReelTwo event pool.
    This also fixes a subtle ordering bug: previously fDomeDrive.setup() was
    called before AmidalaController::setup() (members register before the
    class itself), so homing started with default config values. Now setup()
    is called explicitly at the end of the RoboClaw config block, after all
    parameters from EEPROM/config.txt have been applied.
    [controller.cpp, dome_drive_roboclaw.h]
2026-04-24 Fix random-mode toggle when altdomestick=1 is active
    When alt is held with altdomestick=1, enableAbsoluteStickMode() was
    overwriting fState even when the dome was already in random mode.
    This caused toggleRandomMode() to see isRandomMode()==false and
    re-enable instead of disable, making the toggle always turn random on.
    Two-part fix:
    - Don't engage abs-stick mode at all when random mode is active, so
    the state stays kStateRandom while the alt button is held and the
    toggle check sees the correct value.
    - Save/restore fState across abs-stick engage/disengage so other
    states (e.g. kStateGoToAngle) are also preserved on alt-release.
    Also updates example_config.txt to move the random-togg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
    [example_config.txt]
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2026-04-29 Refactor: reduce repetition and clarify non-obvious code
    - drive_controllers: replace 4 repeated button-number switch blocks with
    DRIVE_BTNFIELD/DOME_BTNFIELD macros, consistent with existing macro style
    - buttons: extract processButtonLayer() helper; processButton/Long/Alt
    become one-line wrappers instead of three identical copies
    - audio: extract sendAllHCRVolumes(v,a,b); used in applyHCRVolume,
    restoreVolumes, and toggleMute
    - config: collapse 7 identical dome-seek else-if blocks (each calling
    applyDomePositionParams) into one chained || expression
    - audio.h: comment the unsigned-wraparound trick on fLastVolumeUpdate init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
    [audio.h, buttons.cpp, config.cpp]
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2026-05-07 Add delays between volume adjustment calls
    It seems HCR has issues if you send volume level commands too fast. So this adds a delay between calls.
    [example_config.txt]
2026-05-21 Port firmware to ESP32-S3 WROOM1 N16R8 (build scaffold)
    Replaces the Mega 2560 target with ESP32-S3. The firmware builds
    clean (`pio run`) and all 454 native unit tests pass (`pio test -e native`).
    Key changes:
    - platformio.ini: ESP32-S3 env only (Mega env removed); lib_ignore for
    AVR-incompatible libs (ReeltwoAudio, LedControl); EspSoftwareSerial
    added so the unmodified HCR library resolves SoftwareSerial.h
    - include/esp32_compat.h: force-included shim; maps setWireTimeout()
    (AVR TwoWire) → setTimeout() (ESP32 TwoWire) without touching HCR source
    - include/pin_config.h: ESP32-S3 GPIO assignments (8 servos, 6 DOUTs,
    SPI/I2C/PPM/analog/SD pins); USB-CDC = Serial, UART0 = Serial0
    -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
    [example_config.txt]
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2026-06-09 Update pin assignments and SPI init for Amidala Board v1.1
    - Remap all GPIO pins to match v1.1 PCB (SPI bus moved to GPIO11/12/13
    to avoid the GPIO35-37 conflict on Octal R8 PSRAM; I2C to GPIO8/9;
    digital outputs to GPIO39-42; SD CS to GPIO10; XBee CS/ATTN/SLEEP
    to GPIO7/16/15)
    - Drop Servo 5-8, Digital 5-6, and RCSEL (removed from v1.1 board)
    - Add XBEE_SLEEP_PIN
    - Switch platformio.ini to 8 MB / qio_qspi memory config with factory
    partition table (avoids OPI PSRAM / GPIO35-37 conflict)
    - Assert all SPI CS pins HIGH before SPI.begin() to prevent spurious
    chip-select on boot; add INPUT_PULLUP on MISO
    - Add SD init retry loop (5 attempts) for slower cards at power-up
    - Add temporary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
    [factory_16MB.csv, factory_8MB.csv]
2026-06-14 Fix servo/digital counts, SD init, PSRAM flag, and README pins for v1.1
    - params.h: S[12]→S[4] and D[8]→D[4] to match ESP32 PCB channel counts
    - config.h: SD.begin() now passes explicit SPI bus; config path uses
    leading slash ("/config.txt") for SD library compatibility
    - platformio.ini: add -DBOARD_HAS_PSRAM for N16R8; remove stale N8R2
    flash/memory overrides
    - README: update all pin tables for v1.1 board (XBee SPI, servos, digital
    outputs, SD CS, I2C — all changed from v1.0 assignments)
    [params.h]
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2026-06-19 fix: update Reeltwo library version to fix servo issues
    There was an upstream issue in the Reeltwo library
    that was preventing the servos from initializing
    and attaching correctly specifically for ESP32-S3.
    This fix bumps that version to 23.5.4, which
    includes the fix.
    [controller.cpp]
2026-06-19 feat: add 5 config sub-pages + toast notifications + shared UI helpers
    Adds fully functional web pages for WiFi, XBee, Audio, RC Radio, and Dome
    Drive — each backed by a new GET /api/config/<name> endpoint and JSON builder.
    All pages use edit-in-place controls that apply changes immediately and persist
    them to config.txt via POST /api/config.
    Also refactors the edit-in-place widget (edit.js) into a shared library:
    - showToast() replaces browser alert() for save feedback
    - buildRow() / buildInput() / dispValue() handle all input types: bool, number,
    select (with labeled options), text, password, and hex
    - buildPage() is a one-call page initializer (fetch → build SCHEMA rows → inject)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
    [wifi_ap.cpp]
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2026-06-19 feat: emergency stop, sound config consolidation, serial command capacity
    Emergency stop:
    - Fixed STOP button injected on every page via edit.js (all config, servos,
    serial commands, monitor pages)
    - POST /api/estop logs to monitor and sends "ESTOP" over the main serial
    bus via sendSerialString(), reaching all connected child boards
    - index.html has its own inline ESTOP since it doesn't use edit.js
    Sound config consolidation:
    - Moved volume, startup, rndon, mindelay, maxdelay, ackon from General
    Settings into Audio page under a new "Sound Playback" section
    - Volume was already on audio page — deduped; general page no longer
    shows it
    Serial command slot capacity on home page:
    - GE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
    [wifi_ap.cpp]
2026-06-19 feat: firmware update page, edit/cancel fixes, E-Stop label
    Firmware update page (/update):
    - File picker (.bin only), warning box, Flash Firmware button with
    confirm dialog before upload begins
    - XHR upload with progress bar (0–85% = upload, 90% = flashing,
    95% = restarting) — progress bar pulses gold during chip-write phase
    - Polls /api/info after restart; shows green success box with new
    version and build date once the board comes back online
    - POST /update handler in wifi_ap.cpp uses ESP32 Update library;
    restarts board on success
    Edit-in-place bug fixes (all config pages):
    - Save/cancel buttons were permanently hidden by CSS .hidden class;
    fixed by using HTML hidden attri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
    [wifi_ap.cpp]
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
